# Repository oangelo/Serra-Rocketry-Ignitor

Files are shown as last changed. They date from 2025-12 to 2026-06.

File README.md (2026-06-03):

# Serra Rocketry Ignitor

Sistema de ignicao remota para foguetes experimentais.

## Visao Geral

Duas estacoes independentes se comunicam via LoRa 433 MHz:

| Estacao | Funcao | MCU |
| --- | --- | --- |
| Comando | Operacao remota e seguranca | Raspberry Pi Pico |
| Ignicao | Acionamento do ignitor | ESP32-C3 SuperMini ou Raspberry Pi Pico |

## Sequencia de Ignicao

1. Operador segura o botao por 5 s.
2. Comando transmite `ARM_CONFIRMED` continuamente.
3. Ignicao executa contagem regressiva (5 bipes).
4. Rele aciona por 2 s.
5. Ignicao envia `IGNITION_COMPLETE`.

## Comece Aqui

| Passo | Guia |
| --- | --- |
| 1. Montar | [docs/INSTALL.md](./docs/INSTALL.md) |
| 2. Gravar firmware | [docs/README_ENVIO.md](./docs/README_ENVIO.md) |
| 3. Testar | [test/README.md](./test/README.md) |
| 4. Diagnosticar problemas | [docs/troubleshooting.md](./docs/troubleshooting.md) |

## Estrutura do Repositorio

```text
ignitor/
├── docs/                 # Guias e referencias
├── firmware/
│   ├── micropython/      # Scripts oficiais (.py)
│   └── data/             # Arquivos web/auxiliares
├── hardware/             # BOM, pinagem e materiais fisicos
├── software/             # Legado/compatibilidade
└── test/                 # Scripts e procedimentos de teste
```

## Componentes Principais

| Qtd | Componente | Uso |
| --- | --- | --- |
| 1 | Raspberry Pi Pico | Estacao de Comando |
| 1 | ESP32-C3 SuperMini | Estacao de Ignicao (principal) |
| 2 | Modulo LoRa SX1278 | Comunicacao 433 MHz |
| 2 | LED amarelo 5mm | Status de link |
| 2 | LED vermelho 5mm | Status de ignicao |
| 2 | Buzzer ativo 5V | Feedback sonoro |
| 1 | Botao de ignicao 22 mm | Acionamento |
| 1 | Rele/MOSFET | Saida para ignitor |
| 2 | Modulo TP4056 | Carga de bateria |

Pinagem completa e BOM: [hardware/README.md](./hardware/README.md).

## Regras de Seguranca

- Botao de ignicao deve ser momentaneo (sem trava).
- O comando precisa ser mantido pelos 5 s completos.
- Perda de sinal por mais de 500 ms deve abortar.
- Sempre usar carga dummy antes de ignitor real.
- Sempre conectar antena LoRa antes de energizar.
- Manter distancia minima de 10 m entre operador e foguete.

## Projeto

Projeto da [Serra Rocketry](https://github.com/Serra-Rocketry).

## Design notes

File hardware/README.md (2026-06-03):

# Hardware - Serra Rocketry Ignitor

## Arquitetura

O sistema possui duas estacoes independentes conectadas por LoRa 433 MHz:

- Estacao de Comando: operada pelo usuario em area segura.
- Estacao de Ignicao: fica proxima ao foguete e aciona o ignitor.

## Lista de Componentes (BOM)

| Item | Qtd | Aplicacao | Observacao |
| --- | --- | --- | --- |
| Raspberry Pi Pico | 1 | Estacao de Comando | MCU RP2040 |
| ESP32-C3 SuperMini | 1 | Estacao de Ignicao | MCU principal de ignicao |
| Modulo LoRa SX1278 433 MHz | 2 | Comando e Ignicao | Um por estacao |
| Antena LoRa 433 MHz | 2 | Comando e Ignicao | Obrigatoria antes de energizar |
| LED amarelo 5 mm | 2 | Status de link | Com resistor |
| LED vermelho 5 mm | 2 | Status de ignicao | Com resistor |
| Buzzer ativo | 2 | Feedback sonoro | Um por estacao |
| Botao de ignicao momentaneo | 1 | Comando | Segurar por 5 s |
| Rele ou MOSFET | 1 | Ignicao | Saida para ignitor |
| TP4056 com protecao | 2 | Carga de bateria | Um por estacao |
| Bateria (Li-ion/LiPo) | 2 | Alimentacao | Definir capacidade |
| Resistores 220 ohms | 4 | LEDs | Dois por estacao |

## Pinagem

### Estacao de Comando - Raspberry Pi Pico

| Pino | Funcao |
| --- | --- |
| GP0 | LoRa MISO |
| GP1 | LoRa CS |
| GP2 | LoRa SCK |
| GP3 | LoRa MOSI |
| GP4 | LoRa RESET |
| GP15 | LoRa DIO0 |
| GP11 | LED amarelo |
| GP12 | LED vermelho |
| GP13 | Botao ignicao |
| GP19 | Buzzer |
| GP25 | LED onboard (link) |

### Estacao de Ignicao - ESP32-C3 SuperMini

Pinagem oficial alinhada ao arquivo `firmware/micropython/estacao_ignicao_esp.py`.

| Pino | Funcao |
| --- | --- |
| GPIO4 | LoRa SCK |
| GPIO6 | LoRa MOSI |
| GPIO5 | LoRa MISO |
| GPIO7 | LoRa CS |
| GPIO3 | LoRa RESET |
| GPIO21 | LoRa DIO0 |
| GPIO20 | LED amarelo |
| GPIO0 | LED vermelho |
| GPIO1 | Buzzer |
| GPIO10 | Rele/MOSFET (ignitor) |
| GPIO8 | LED interno de link |

### Estacao de Ignicao - Raspberry Pi Pico (legado)

| Pino | Funcao |
| --- | --- |
| GP0 | LoRa MISO |
| GP1 | LoRa CS |
| GP2 | LoRa SCK |
| GP3 | LoRa MOSI |
| GP4 | LoRa RESET |
| GP15 | LoRa DIO0 |
| GP11 | LED amarelo |
| GP12 | LED vermelho |
| GP19 | Buzzer |
| GP26 | Rele/MOSFET (ignitor) |
| GP25 | LED onboard (link) |

## Sequencia de Operacao

1. Comando envia `ARM_CONFIRMED` enquanto o botao e mantido.
2. Ignicao confirma com `ACK` e inicia contagem de 5 s.
3. Se houver `ABORT` ou perda de sinal > 500 ms, ciclo e cancelado.
4. Ao final da contagem, saida de ignicao ativa por 2 s.
5. Ignicao envia `IGNITION_COMPLETE`.

## Seguranca

- Sempre conectar antena LoRa antes de energizar.
- Usar botao momentaneo (sem trava).
- Testar com carga dummy antes de ignitor real.
- Manter distancia minima de 10 m em testes operacionais.

## Galeria (Tamanho Padronizado)

Todas as imagens abaixo usam largura padrao de 320 px para manter consistencia visual no documento.

<!-- markdownlint-disable MD033 -->

### Raspberry Pi Pico (Comando)

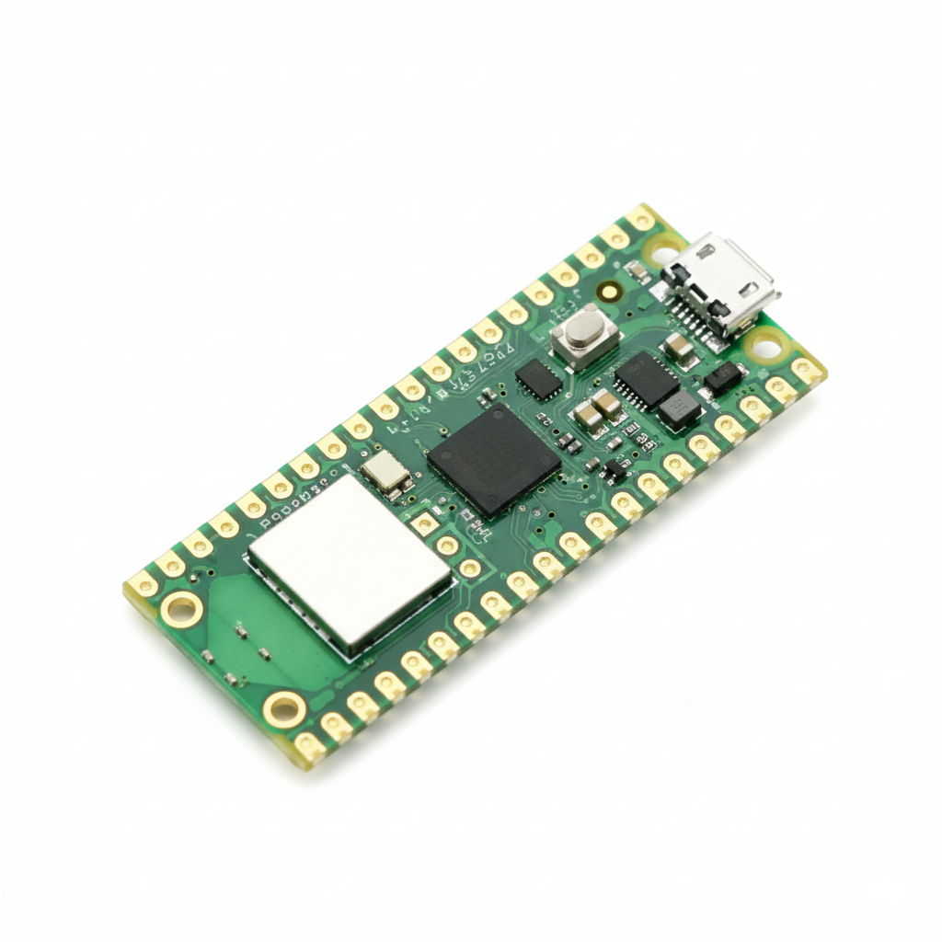
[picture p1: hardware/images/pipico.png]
Raspberry Pi Pico


### Modulo LoRa SX1278

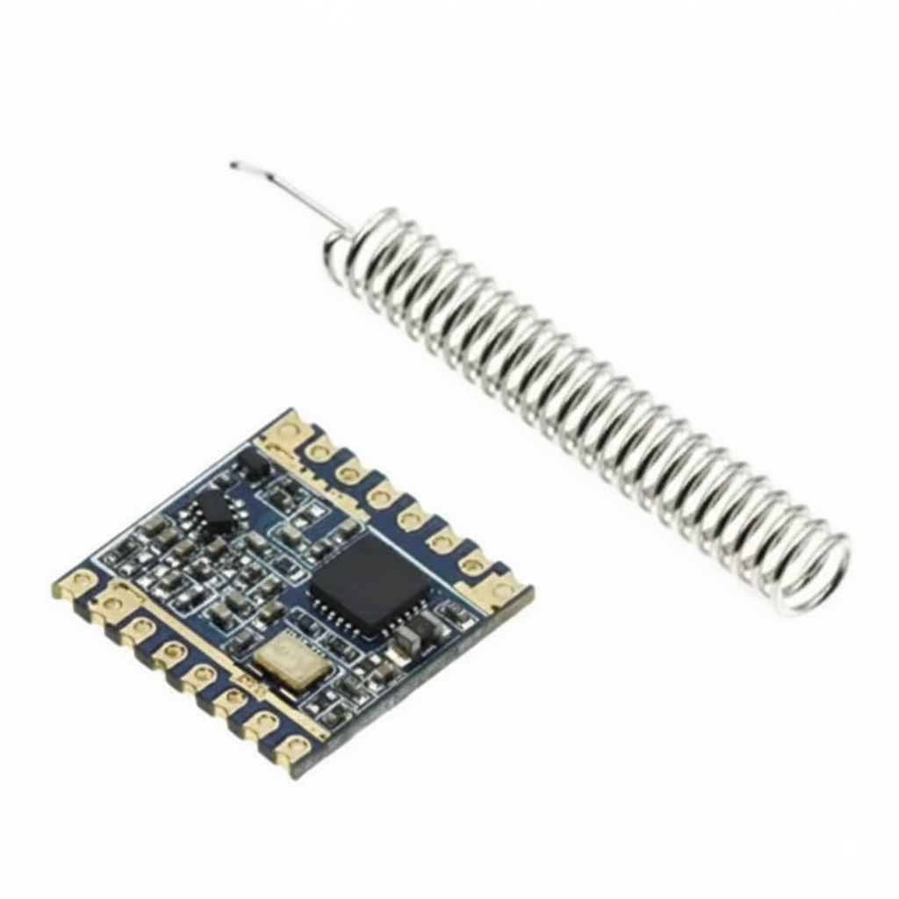
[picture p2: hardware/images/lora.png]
Modulo LoRa SX1278


### Botao de Energia

Botao de energia

### Botao de Ignicao

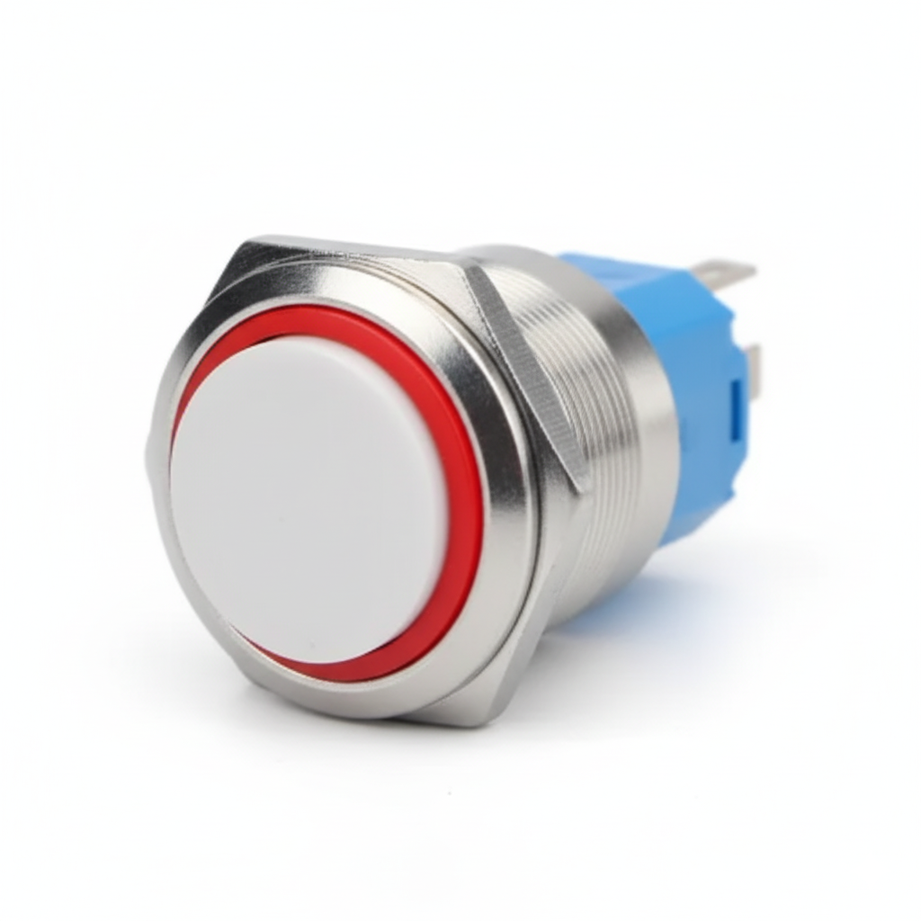
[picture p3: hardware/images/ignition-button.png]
Botao de ignicao


### Esquematico - Estacao de Comando

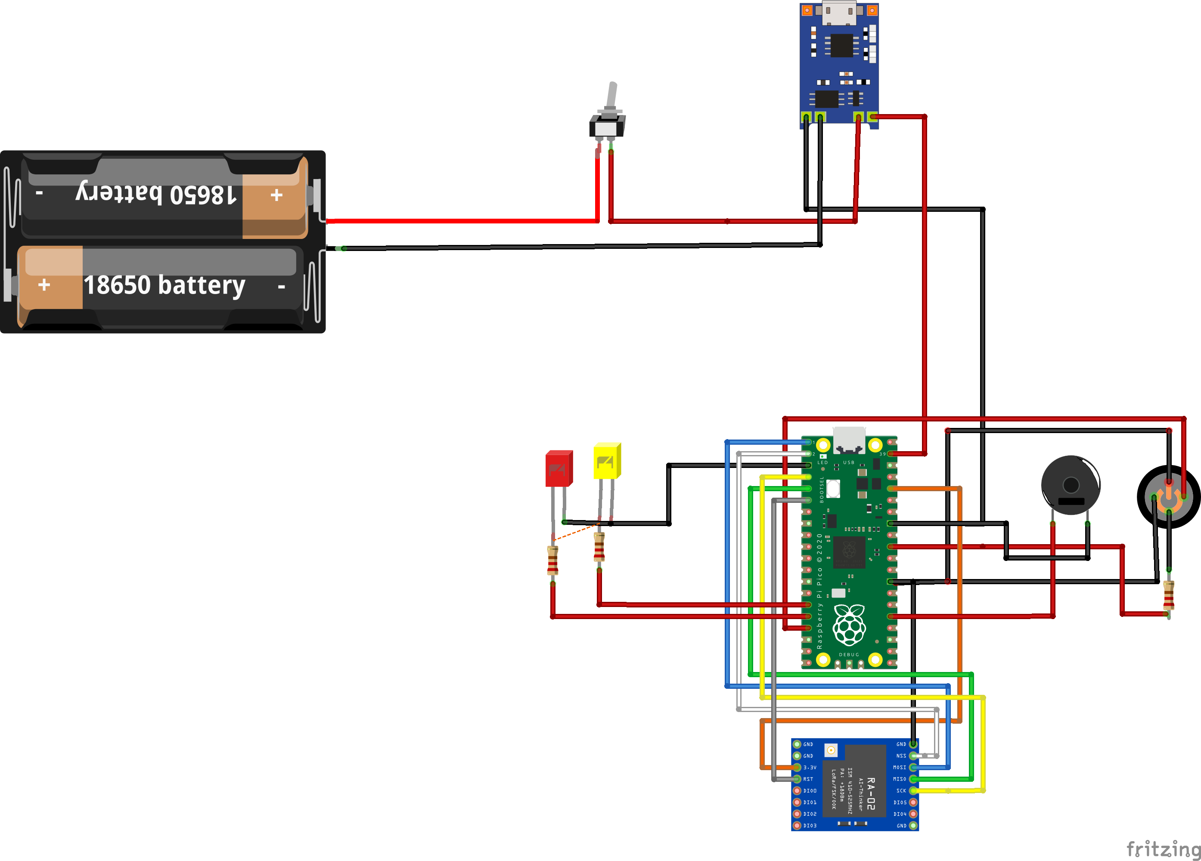
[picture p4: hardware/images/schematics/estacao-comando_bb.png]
Esquematico da estacao de comando


### Esquematico - Estacao de Ignicao

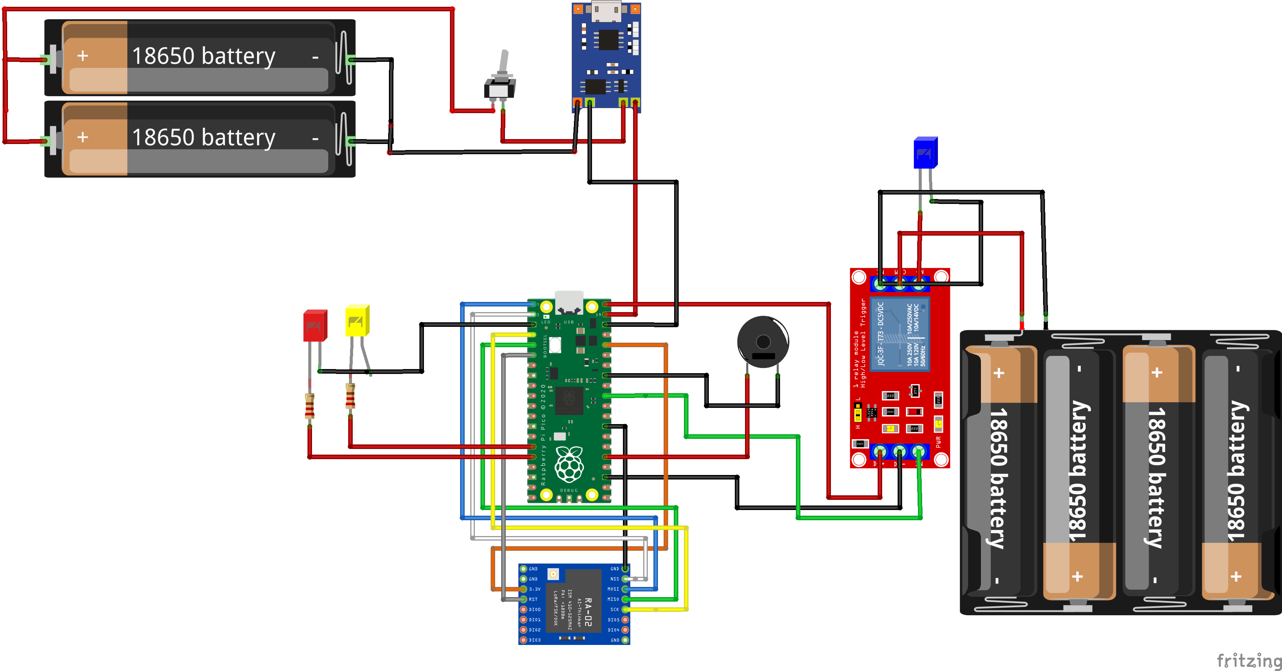
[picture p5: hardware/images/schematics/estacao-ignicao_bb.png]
Esquematico da estacao de ignicao


<!-- markdownlint-enable MD033 -->

## Pastas de Hardware

- [3d_models](./3d_models): modelos 3D dos cases.
- [fritzing](./fritzing): arquivos de esquematico/layout.
- [gerbers](./gerbers): arquivos de fabricacao PCB.
- [images](./images): imagens e esquemas.

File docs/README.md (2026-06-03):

# Documentacao do Ignitor

Guias praticos para montar, operar, testar e manter o sistema.

## Fluxo Recomendado

Montar hardware -> Gravar firmware -> Testar -> Operar.

| Etapa | Documento |
| --- | --- |
| Montagem | [INSTALL.md](./INSTALL.md#3-montagem-de-hardware) |
| Envio de firmware | [README_ENVIO.md](./README_ENVIO.md) |
| Testes de bancada/campo | [../test/README.md](../test/README.md) |
| Troubleshooting | [troubleshooting.md](./troubleshooting.md) |
| Protocolo | [README_API.md](./README_API.md) |
| Registro de resultados | [README_TESTS.md](./README_TESTS.md) |

## Referencias Rapidas

- Pinagem: [../hardware/README.md#pinagem](../hardware/README.md#pinagem)
- BOM: [../hardware/README.md#lista-de-componentes-bom](../hardware/README.md#lista-de-componentes-bom)
- Sequencia operacional: [../hardware/README.md#sequencia-de-operacao](../hardware/README.md#sequencia-de-operacao)

## Avisos Importantes

- Sempre usar carga dummy (lampada/LED) durante testes.
- Nunca energizar modulo LoRa sem antena conectada.
- Manter distancia minima de 10 m do foguete em testes de campo.

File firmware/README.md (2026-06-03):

# Firmware - Serra Rocketry Ignitor

Repositorio de firmware e arquivos auxiliares do projeto.

## Estrutura Atual

```text
firmware/
├── micropython/
│   ├── estacao_comando.py
│   ├── estacao_ignicao.py
│   ├── estacao_ignicao_esp.py
│   ├── sx127x.py
│   └── config_lora.py
└── data/
    ├── index.html
    ├── script.js
    ├── style.css
    └── hammer.min.js
```

## Firmware Oficial (MicroPython)

| Estacao | Arquivo | Placa alvo | Salvar como |
| --- | --- | --- | --- |
| Comando | [micropython/estacao_comando.py](./micropython/estacao_comando.py) | Raspberry Pi Pico | `main.py` |
| Ignicao (principal) | [micropython/estacao_ignicao_esp.py](./micropython/estacao_ignicao_esp.py) | ESP32-C3 SuperMini | `main.py` |
| Ignicao (legado) | [micropython/estacao_ignicao.py](./micropython/estacao_ignicao.py) | Raspberry Pi Pico | `main.py` |

Arquivos de suporte:

- [micropython/sx127x.py](./micropython/sx127x.py)
- [micropython/config_lora.py](./micropython/config_lora.py)

Pinagem completa e BOM:

- [../hardware/README.md](../hardware/README.md#pinagem)

## Pasta data

A pasta [data](./data) contem arquivos web auxiliares para experimentos e interfaces locais.
Ela nao substitui os scripts MicroPython de operacao das estacoes.

## Gravacao nas Placas

Guia rapido de envio:

- [../docs/README_ENVIO.md](../docs/README_ENVIO.md)

Guia de instalacao completo:

- [../docs/INSTALL.md](../docs/INSTALL.md#4-gravar-firmware)

## Debug Serial

```bash
screen /dev/ttyACM0 115200
```

Exemplo de logs esperados:

```text
[LoRa] SX1278 inicializado em 433 MHz.
[CMD] Link com ignicao: OK
[CMD] ACK recebido da base de ignicao.
[CMD] IGNITION_COMPLETE recebido.
```

## Seguranca

- Sempre conectar antena LoRa antes de energizar.
- Testar primeiro com carga dummy (LED/lampada).
- Manter distancia segura durante qualquer teste operacional.

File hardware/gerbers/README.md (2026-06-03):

# Gerbers

Arquivos de fabricacao de PCB (Gerber/Drill) quando houver placa dedicada.

Sugestao de organizacao:

- uma subpasta por revisao de hardware
- incluir README de versao e fornecedor

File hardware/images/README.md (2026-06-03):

# Imagens de Hardware

Imagens de componentes, montagem e documentacao visual.

Subpastas:

- `schematics/` para esquemas exportados

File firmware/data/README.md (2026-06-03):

# Firmware Data

Arquivos auxiliares do firmware legado em Arduino/Web UI:

- `index.html`
- `script.js`
- `style.css`
- `hammer.min.js`

Conteudo usado em experimentos e interfaces locais.

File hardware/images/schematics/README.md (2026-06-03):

# Schematics

Imagens dos esquematicos das estacoes de comando e ignicao.

Use nomes descritivos e mantenha resolucao suficiente para leitura de pinos.

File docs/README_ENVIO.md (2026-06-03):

# Envio de Firmware para Pico e ESP32-C3

Este guia mostra como enviar os scripts MicroPython para as placas do projeto.

## Arquivos por Placa

### Pico da Estacao de Comando

- `firmware/micropython/estacao_comando.py` (salvar como `main.py`)
- `firmware/micropython/sx127x.py` (opcional)
- `firmware/micropython/config_lora.py` (opcional)

### Pico da Estacao de Ignicao

- `firmware/micropython/estacao_ignicao.py` (salvar como `main.py`)
- `firmware/micropython/sx127x.py` (opcional)
- `firmware/micropython/config_lora.py` (opcional)

### ESP32-C3 da Estacao de Ignicao

- `firmware/micropython/estacao_ignicao_esp.py` (salvar como `main.py`)
- `firmware/micropython/sx127x.py` (opcional, existe fallback nativo)

## 1. Descobrir Porta Serial

```bash
ls /dev/ttyACM* /dev/ttyUSB*
```

Exemplo comum:

- Comando: `/dev/ttyACM0`
- Ignicao Pico: `/dev/ttyACM1`
- Ignicao ESP32-C3: `/dev/ttyUSB0`

## 2. Envio com ampy

### 2.1 Estacao de Comando (Pico)

```bash
ampy --port /dev/ttyACM0 put firmware/micropython/estacao_comando.py main.py
ampy --port /dev/ttyACM0 ls
```

### 2.2 Estacao de Ignicao (Pico)

```bash
ampy --port /dev/ttyACM1 put firmware/micropython/estacao_ignicao.py main.py
ampy --port /dev/ttyACM1 ls
```

### 2.3 Estacao de Ignicao (ESP32-C3)

```bash
ampy --port /dev/ttyUSB0 put firmware/micropython/estacao_ignicao_esp.py main.py
ampy --port /dev/ttyUSB0 ls
```

## 3. Envio com Thonny

1. Abrir Thonny.
2. Selecionar interpretador MicroPython da placa.
3. Abrir arquivo em `firmware/micropython/`.
4. Salvar no dispositivo como `main.py`.

## 4. Logs Seriais

```bash
screen /dev/ttyACM0 115200
```

Trocar a porta conforme a placa conectada.

## 5. Regra Importante de Antena

Antes de energizar ou testar, confirme as duas antenas LoRa conectadas e apertadas. Sem antena, o radio pode inicializar, mas o enlace PING/PONG nao fecha de forma confiavel.

## 6. Erros Comuns

### Permissao negada na serial

```bash
sudo usermod -aG dialout $USER
```

Depois, encerre e reabra a sessao.

### Placa nao aparece em `/dev/ttyACM*` ou `/dev/ttyUSB*`

- Trocar cabo USB (dados, nao apenas carga).
- Testar outra porta USB.
- Regravar MicroPython na placa.

## Creditos da Biblioteca LoRa

Projeto baseado/adaptado de:

- [SX127x driver for (Micro)Python on ESP8266/ESP32/Raspberry_Pi](https://github.com/Wei1234c/SX127x_driver_for_MicroPython_on_ESP8266)

Arquivos locais relacionados:

- `firmware/micropython/sx127x.py`
- `firmware/micropython/config_lora.py`

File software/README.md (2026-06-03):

# Software (Legado)

Esta pasta foi mantida por compatibilidade historica.

Os scripts oficiais de firmware MicroPython foram movidos para:

- `../firmware/micropython/`

Nao adicione novos firmwares aqui.

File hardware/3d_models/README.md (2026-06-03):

# Modelos 3D

Arquivos de modelos 3D dos cases e suportes mecanicos do sistema.

Subpastas:

- `comando/`
- `ignição/`

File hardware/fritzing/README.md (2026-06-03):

# Fritzing

Arquivos `.fzz` dos esquemas de montagem das estacoes.

Use esta pasta para manter os diagramas editaveis de protoboard e conexoes.

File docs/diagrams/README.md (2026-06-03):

# Diagramas

Esta pasta concentra diagramas de arquitetura, protocolo e fluxo de operacao.

Padrao recomendado:

- Nome curto e descritivo
- Formato editavel (ex.: `.drawio`, `.mermaid`)
- Exportacao em PNG/SVG quando necessario

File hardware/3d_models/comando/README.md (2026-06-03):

# Modelos 3D - Comando

Modelos STEP da caixa da estacao de comando.

Arquivos tipicos:

- laterais
- tampa superior/inferior

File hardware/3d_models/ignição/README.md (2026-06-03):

# Modelos 3D - Ignicao

Modelos STEP da caixa da estacao de ignicao.

Esta pasta contem as pecas mecanicas para impressao/prototipagem.

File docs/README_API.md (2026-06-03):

# API e Protocolo

> Protocolo de comunicação entre as duas estações via LoRa 433 MHz.

## Camada Física

| Parametro | Valor |
| --- | --- |
| Frequência | 433 MHz |
| Largura de banda | 125 kHz |
| Spreading Factor | 7 |
| Coding Rate | 4/5 |
| Potência TX | 17 dBm |

## Mensagens

| Mensagem | Direcao | Uso |
| --- | --- | --- |
| PING | Comando → Ignição | Teste de conexão |
| PONG | Ignição → Comando | Resposta ao PING |
| ARM_CONFIRMED | Comando → Ignição | Comando mantido (retransmitido a cada 200 ms) |
| ACK | Ignição → Comando | Confirma recebimento e início da contagem |
| ABORT | Comando → Ignição | Cancela imediatamente |
| IGNITION_COMPLETE | Ignição → Comando | Ciclo concluído |

## Diagrama de Estados

```text
        ┌──────────┐
        │  IDLE    │
        └────┬─────┘
             │ PONG
        ┌────▼─────┐
   ┌────│ CONNECTED│◄──┐
   │    └────┬─────┘   │
   │         │ARM_CONFIRMED
   │    ┌───▼──────┐   │ timeout
   │    │ COUNTDOWN │───┴───┘
   │    └────┬─────┘
   │         │ fim (5s)
   │    ┌───▼──────┐
   └───►│ IGNITION │──────► ACK
        └──────────┘
```

## Timeouts

| Parametro | Valor |
| --- | --- |
| Retransmissão ARM_CONFIRMED | 200 ms |
| Timeout de comando (Ignição) | 500 ms |
| Timeout de link (Comando) | 3000 ms |
| Espera após IGNITION_COMPLETE | 3000 ms |

## Regras de Segurança

- Contagem só inicia após `ACK` recebido
- Perda de `ARM_CONFIRMED` por > 500 ms aborta
- Soltar botão envia `ABORT` imediatamente
- Verificação final antes de acionar relé

Consulte [../firmware/micropython/estacao_ignicao_esp.py](../firmware/micropython/estacao_ignicao_esp.py) para implementacao de referencia.

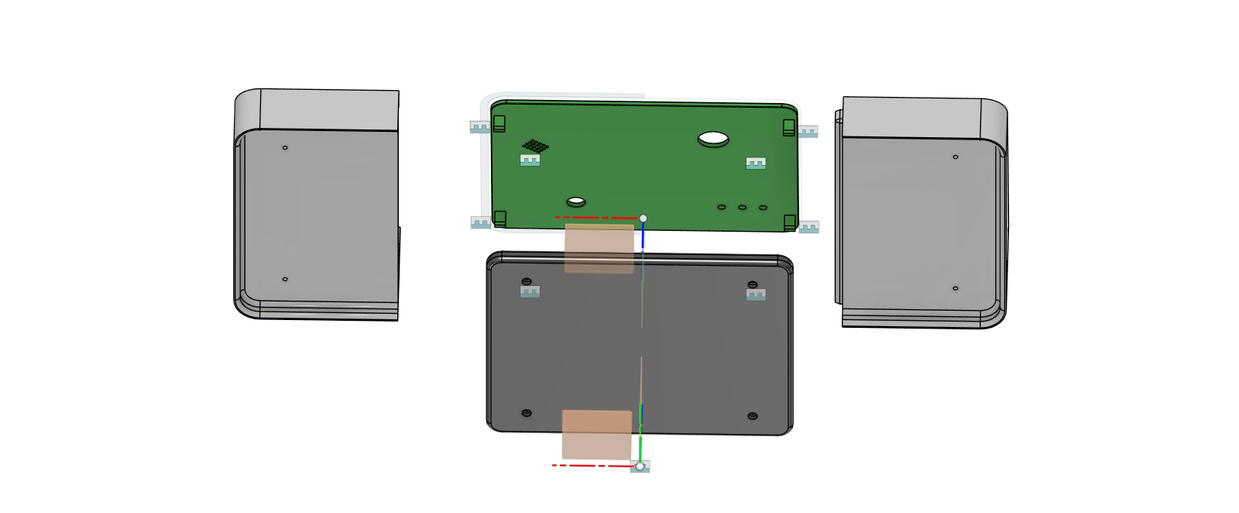
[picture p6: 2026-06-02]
hardware/3d_models/comando/caixa ignitor 2.png

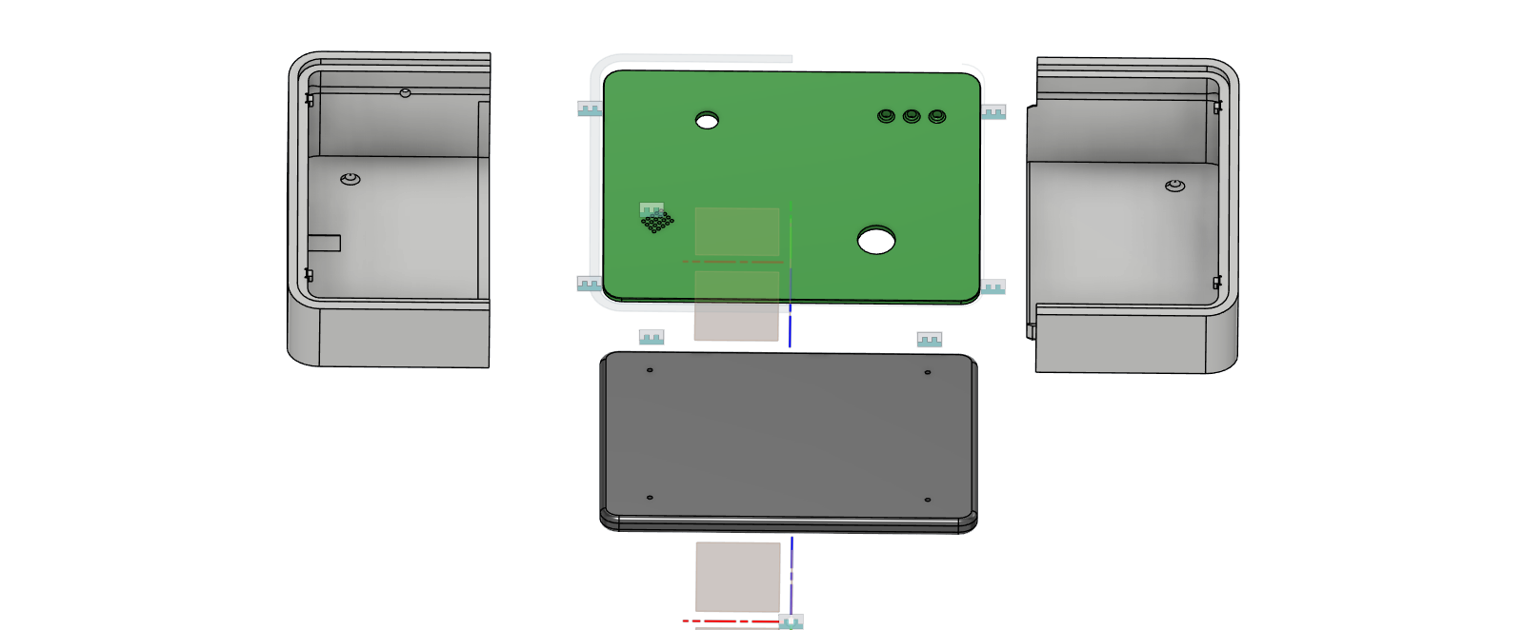
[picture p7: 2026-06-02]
hardware/3d_models/comando/caixa ignitor v16.png

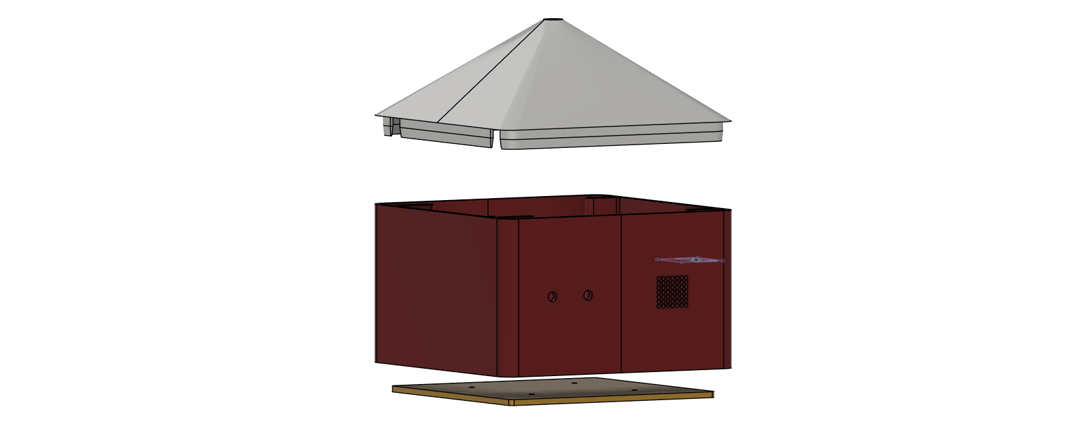
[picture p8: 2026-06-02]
hardware/3d_models/ignição/BASEIGNIÇÃO v9.png

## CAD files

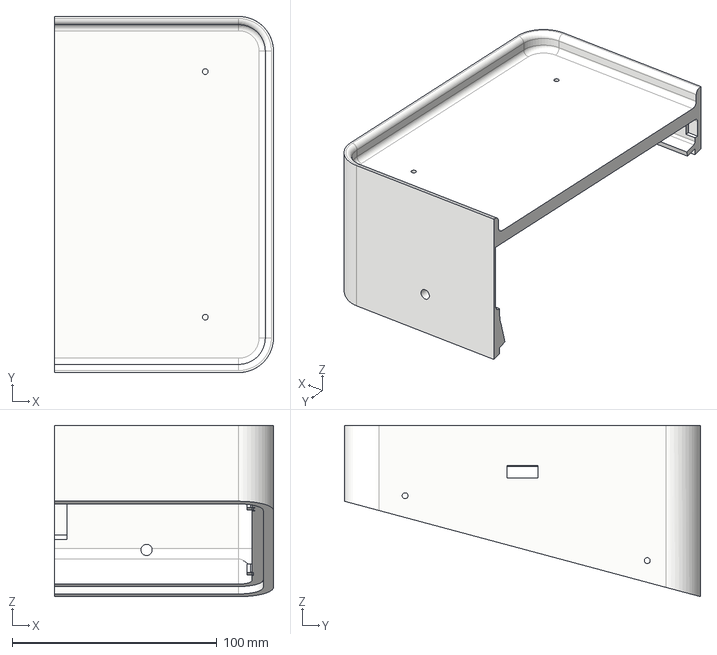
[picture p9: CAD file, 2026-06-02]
hardware/3d_models/comando/lado1.step
107.0 x 174.0 x 83.7 mm

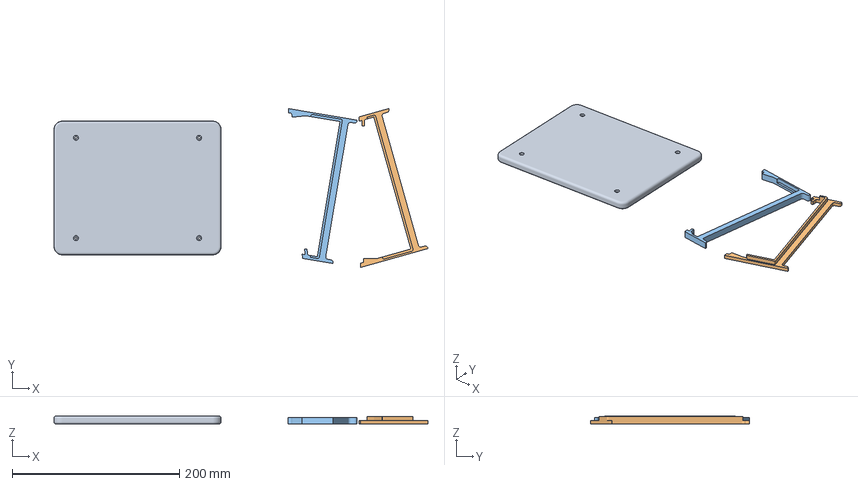
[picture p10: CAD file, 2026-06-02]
hardware/3d_models/ignitorserra.3mf
447.6 x 190.2 x 10.0 mm
tampabaixo.step
lado2.step
lado1.step

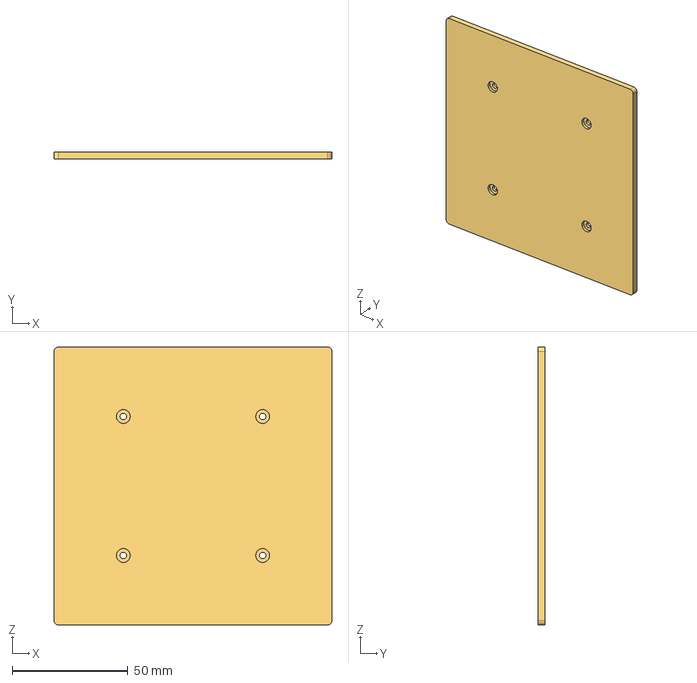
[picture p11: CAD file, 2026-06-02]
hardware/3d_models/ignição/TAMPABAIXO.step
120.0 x 3.00 x 120.0 mm

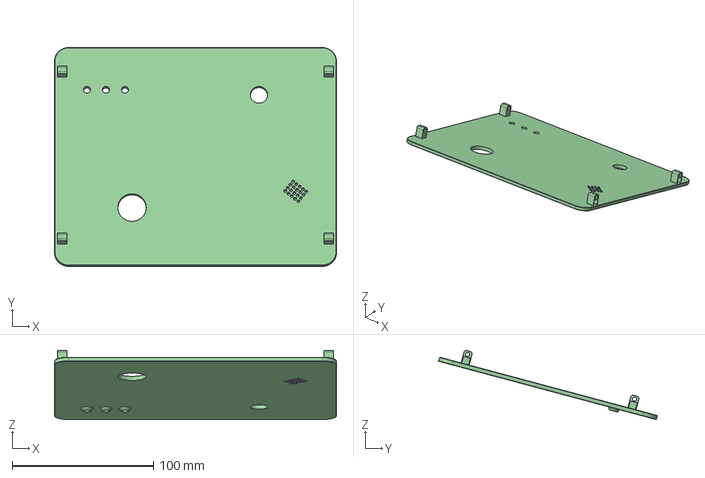
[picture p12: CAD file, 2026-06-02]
hardware/3d_models/comando/tampacima.step
200.0 x 155.2 x 49.0 mm
caixa
Componente3

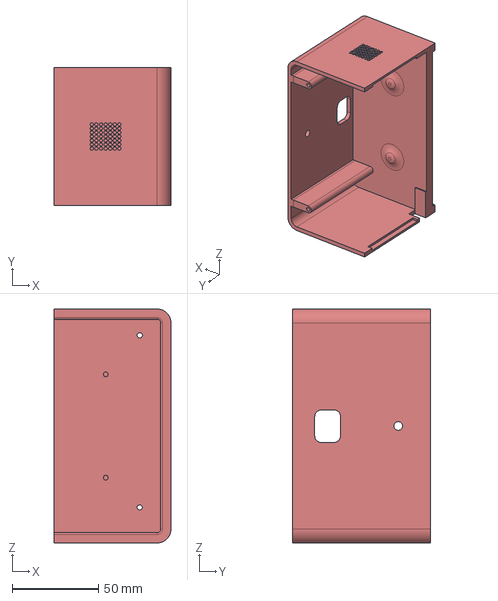
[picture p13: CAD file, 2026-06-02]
hardware/3d_models/ignição/caixapart2.step
68.0 x 80.0 x 136.0 mm

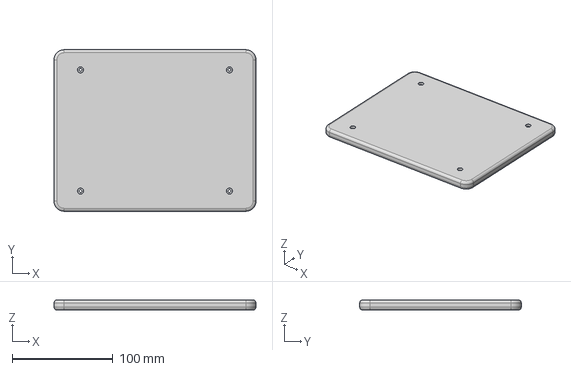
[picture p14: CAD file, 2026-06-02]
hardware/3d_models/comando/tampabaixo.step
200.0 x 160.0 x 10.0 mm

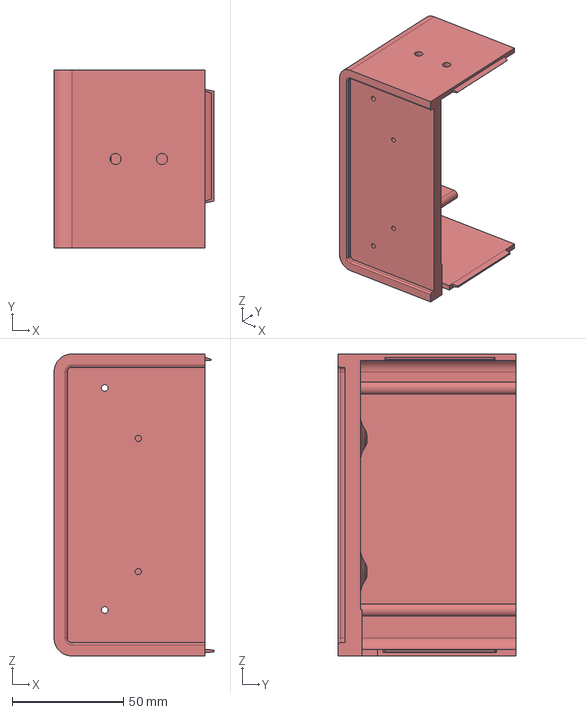
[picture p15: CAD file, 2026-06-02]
hardware/3d_models/ignição/caixapart1.step
72.0 x 80.0 x 136.0 mm

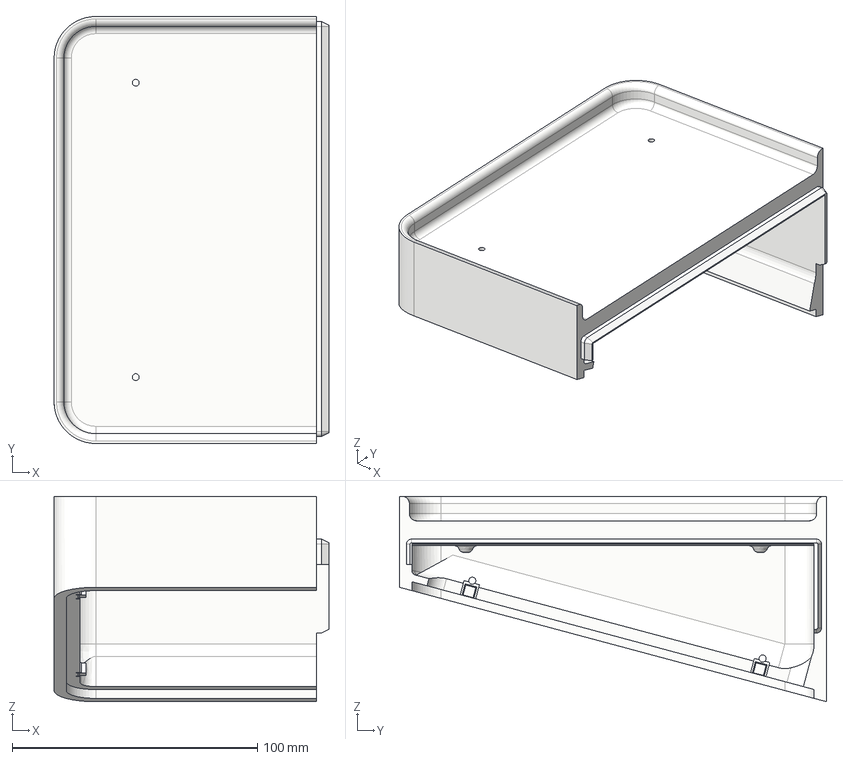
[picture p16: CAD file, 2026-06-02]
hardware/3d_models/comando/lado2.step
112.0 x 174.0 x 83.7 mm

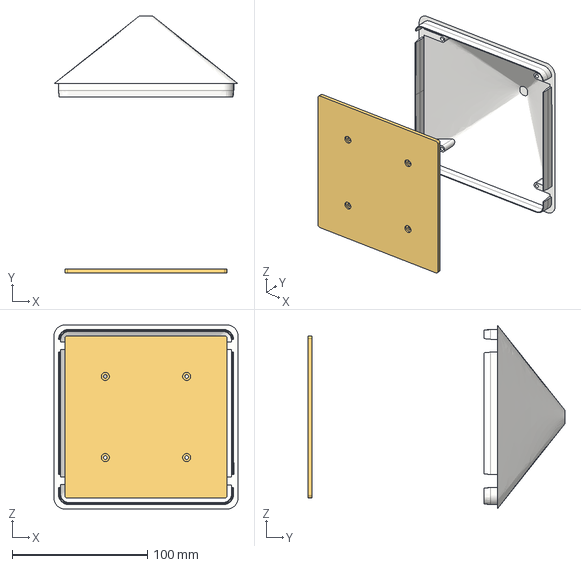
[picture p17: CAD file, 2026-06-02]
hardware/3d_models/ignição/TAMPACIMA.step
136.0 x 190.0 x 136.0 mm

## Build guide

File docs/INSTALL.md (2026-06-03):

# Guia de Instalacao

Resumo: monte -> grave -> teste -> opere.

## Indice

| Secao | Topico |
| --- | --- |
| [1](#1-pre-requisitos) | Pre-requisitos |
| [2](#2-preparar-ambiente) | Preparar ambiente |
| [3](#3-montagem-de-hardware) | Montagem de hardware |
| [4](#4-gravar-firmware) | Gravar firmware |
| [5](#5-validar-operacao) | Validar operacao |
| [6](#6-integracao-com-ignitor-real) | Integracao com ignitor real |
| [7](#7-troubleshooting) | Troubleshooting |

## 1. Pre-requisitos

### Software

- Python 3.8+.
- Dependencias do projeto: `pip install -r requirements.txt`.
- Thonny IDE (recomendado) ou VS Code com extensao MicroPython.

### Hardware

- Multimetro.
- Fonte/bateria adequada.
- Ferramentas de montagem (ferro de solda, estanho, etc.).

## 2. Preparar Ambiente

```bash
git clone https://github.com/Serra-Rocketry/ignitor.git
cd ignitor
pip install -r requirements.txt
```

## 3. Montagem de Hardware

### 3.1 Estacao de Comando

- 1x Raspberry Pi Pico.
- 1x SX1278 433 MHz.
- 2x LEDs + resistores.
- 1x buzzer.
- 1x botao de ignicao.

Pinagem detalhada: [../hardware/README.md](../hardware/README.md#pinagem).

### 3.2 Estacao de Ignicao

- 1x ESP32-C3 SuperMini (ou Pico, variante legada).
- 1x SX1278 433 MHz.
- 2x LEDs + resistores.
- 1x buzzer.
- 1x rele/MOSFET para ignitor.

Pinagem detalhada: [../hardware/README.md](../hardware/README.md#pinagem).

### 3.3 Checklist Antes de Energizar

1. Verificar curto e polaridade com multimetro.
2. Confirmar conexoes SPI.
3. Confirmar antenas LoRa conectadas e apertadas.
4. Nao energizar SX1278 sem antena.

## 4. Gravar Firmware

Scripts oficiais:

- `firmware/micropython/estacao_comando.py`
- `firmware/micropython/estacao_ignicao.py` (Pico)
- `firmware/micropython/estacao_ignicao_esp.py` (ESP32-C3)
- `firmware/micropython/sx127x.py` (compatibilidade)
- `firmware/micropython/config_lora.py` (compatibilidade)

### 4.1 Envio com `ampy`

```bash
# Estacao de Comando (Pico)
ampy --port /dev/ttyACM0 put firmware/micropython/estacao_comando.py main.py

# Estacao de Ignicao (Pico)
ampy --port /dev/ttyACM1 put firmware/micropython/estacao_ignicao.py main.py

# Estacao de Ignicao (ESP32-C3)
ampy --port /dev/ttyUSB0 put firmware/micropython/estacao_ignicao_esp.py main.py
```

## 5. Validar Operacao

1. Ligar estacao de comando.
2. Ligar estacao de ignicao.
3. Confirmar `PING/PONG` no serial e LED amarelo de link.
4. Executar teste com carga dummy no lugar do ignitor.

Se o enlace nao subir, checar antena primeiro.

## 6. Integracao com Ignitor Real

Realizar apenas em ambiente seguro e com procedimento validado.

1. Confirmar continuidade do ignitor.
2. Confirmar antena conectada antes de energizar.
3. Posicionar operador a distancia segura (>= 10 m).
4. Executar sequencia completa.

## 7. Troubleshooting

| Problema | Possivel causa | Acao |
| --- | --- | --- |
| Sem link LoRa | Antena ausente/solta | Reapertar antenas e reiniciar |
| Buzzer sem som | Ligacao incorreta | Verificar pino de buzzer da placa |
| Ignitor nao aciona | Rele/MOSFET | Testar saida com carga dummy |

Detalhes: [troubleshooting.md](./troubleshooting.md).

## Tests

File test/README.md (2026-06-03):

# Plano de Testes

## Objetivos

- Validar comunicacao LoRa bidirecional entre as estacoes.
- Confirmar sequencia de seguranca com botao mantido por 5 s.
- Testar feedback visual (LEDs) e sonoro (buzzers).
- Verificar abort manual e abort por timeout.

## Requisito Inicial

Antes de qualquer teste, confirme as duas antenas LoRa conectadas e apertadas.

## Testes Prioritarios

### 1. Comunicacao LoRa Basica

Objetivo: confirmar `PING/PONG` de forma estavel.

Checklist:

- [ ] Comando envia `PING` e ignicao responde `PONG`.
- [ ] LED amarelo acende nas duas estacoes quando conectadas.
- [ ] Ao desligar uma estacao, timeout de link ocorre conforme esperado.

Procedimento:

1. Ligar as duas estacoes a 1 m.
2. Observar serial e LEDs.
3. Repetir em 10 m, 50 m, 100 m e 500 m.
4. Registrar RSSI e perdas.

### 2. Sequencia de Ignicao Completa

Objetivo: validar contagem e acionamento final.

Checklist:

- [ ] Botao mantido por 5 s.
- [ ] LED vermelho pisca durante contagem.
- [ ] Buzzer da ignicao emite 5 apitos.
- [ ] Saida de ignicao aciona por 2 s.
- [ ] Comando recebe `IGNITION_COMPLETE`.

Procedimento:

1. Conectar carga dummy na saida de ignicao.
2. Segurar botao de ignicao por 5 s.
3. Confirmar acionamento apenas no final da contagem.

### 3. Abort Manual

Objetivo: garantir cancelamento ao soltar o botao.

Checklist:

- [ ] Botao solto antes de 5 s envia `ABORT`.
- [ ] Contagem para imediatamente.
- [ ] Ignitor nao e acionado.

Procedimento:

1. Iniciar contagem.
2. Soltar no 2o ou 3o apito.
3. Repetir cinco vezes.

### 4. Abort por Timeout

Objetivo: abortar em perda de `ARM_CONFIRMED`.

Checklist:

- [ ] Durante contagem, interromper link/comando.
- [ ] Ignicao detecta timeout (> 500 ms).
- [ ] Estado de erro e sinalizado.
- [ ] Ignitor nao e acionado.

### 5. Alcance em Campo

Objetivo: determinar alcance confiavel do enlace.

Checklist:

- [ ] Executar testes em linha de visao.
- [ ] Avaliar 50 m, 100 m, 200 m, 500 m e 1 km.
- [ ] Registrar taxa de sucesso e RSSI.

## Scripts de Bancada

Arquivos da pasta `test/`:

- `mp_lora_radio.py`: modulo comum de radio.
- `mp_teste_conexao.py`: link `PING/PONG` com estatisticas.
- `mp_teste_envio_dados.py`: envio `DATA` com `ACK` e retry.

Uso em duas placas:

1. Copiar `mp_lora_radio.py` e o script desejado.
2. Ajustar `ROLE` no topo.
3. `initiator` e `responder` para teste de conexao.
4. `tx` e `rx` para teste de envio de dados.

Os scripts seguem a configuracao de radio em `firmware/micropython/`.

## Execucao

### Testes Automatizados

```bash
cd test
python run_tests.py --all
python run_tests.py --lora
python run_tests.py --ignition
```

### Testes Manuais

Seguir os procedimentos acima e registrar resultado em `docs/README_TESTS.md`.

## Seguranca

- Nunca usar ignitor real em bancada.
- Sempre usar carga dummy.
- Manter pessoas a pelo menos 10 m.
- Usar EPI adequado durante testes energizados.

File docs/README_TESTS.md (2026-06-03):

# Resultados de Testes

## Matriz de Testes

| ID | Tipo | Descrição | Critério | Status |
|----|---|---|---|---|
| LORA-01 | LoRa | PING/PONG bidirecional | PONG < 500 ms | Pendente |
| LORA-02 | LoRa | RSSI a 50 m | RSSI > -80 dBm | Pendente |
| LORA-03 | LoRa | RSSI a 500 m | RSSI > -120 dBm | Pendente |
| IGN-01 | Ignição | Sequência completa (5 s) | Relé aciona após 5 s | Pendente |
| IGN-02 | Ignição | Contagem de apitos | 5 apitos audíveis | Pendente |
| IGN-03 | Ignição | LEDs | Vermelho pisca → sólido | Pendente |
| ABORT-01 | Segurança | Abort manual | Botão solto cancela | Pendente |
| ABORT-02 | Segurança | Abort por timeout | Perda > 500 ms cancela | Pendente |

**Status**: Pendente | Passou | Falhou

## Registro de Sessões

| Data | ID | Resultado | Distância | RSSI | Observações |
|---|----|---|---|---|---|
| - | - | - | - | - | - |

- Logs salvos em `test/logs/` (não versionado)
- Vídeos/fotos grandes linkados externamente

## Procedimento

Após cada sessão:

1. Preencher registro acima
2. Salvar logs em `test/logs/sessao_YYYYMMDD.csv`
3. Linkar evidências no registro

Consulte [test/README.md](../test/README.md) para procedimentos detalhados.

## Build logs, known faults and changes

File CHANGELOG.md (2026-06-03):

# Changelog

Baseado em [Keep a Changelog](https://keepachangelog.com) e [Versionamento Semântico](https://semver.org).

## [Unreleased]

### Planejado
- Firmware validado
- Testes de campo
- Cases 3D

## [1.0.0] - 2026-04-21

### Adicionado
- **Hardware**: BOM e pinagem para ESP32-C3 SuperMini (Estação de Ignição)
- **Firmware**: `estacao_ignicao_esp.py` para ESP32-C3
- **Protocolo**: Documentação simplificada com diagrama de estados
- **Documentação**: Repositório refatorado (arquivos renomeados, índice consolidado)

### Alterado
- **BOM**: Comando usa Raspberry Pi Pico; Ignição usa ESP32-C3 SuperMini
- **Estrutura**: docs/ renomeado para padrão consistente

## [0.1.0] - 2024-11-14

### Adicionado
- Estrutura inicial do repositório
- Documentação de arquitetura
- BOM e pinagem Raspberry Pi Pico
- Protocolo LoRa 433 MHz
- Guias de instalação e troubleshooting
- Plano de testes

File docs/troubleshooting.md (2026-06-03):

# Troubleshooting

## Problemas Comuns

| Sintoma | Causa provavel | Acao recomendada |
| --- | --- | --- |
| Nao conecta (`PING/PONG`) | Antena ausente/solta | Reconectar as duas antenas e reiniciar |
| Link instavel | Sinal fraco/interferencia | Aproximar estacoes e medir RSSI |
| Buzzer sem som | Pino incorreto ou buzzer danificado | Verificar pino da placa e testar buzzer |
| Botao nao responde | Ligacao/pull-up | Validar continuidade e pino de entrada |
| Ignitor nao aciona | Rele/MOSFET ou pino de saida | Testar saida com carga dummy |
| Contagem aborta | Perda de `ARM_CONFIRMED` | Melhorar enlace e reduzir distancia |

## Checklist Rapido

1. Bateria ok e alimentacao estavel.
2. Antenas conectadas antes de energizar.
3. Firmware correto gravado em cada estacao.
4. Frequencia e pinagem conferidas em `firmware/micropython/estacao_*.py`.
5. Cabo USB de dados para programacao/logs.

## Diagnostico por Serial

Abrir monitor serial em 115200 baud.

Exemplo de fluxo esperado:

```text
[LoRa] SX1278 inicializado em 433 MHz.
[CMD] Link com ignicao: OK
[LoRa TX] -> PING
[LoRa RX] <- PONG
```

## Casos Especificos

### Nao recebe `ARM_CONFIRMED`

1. Confirmar que a estacao de comando esta em estado conectado.
2. Conferir frequencia em ambas as placas.
3. Conferir antena e conexoes SPI.

### Aborta no meio da contagem

1. Manter botao pressionado durante os 5 s.
2. Validar qualidade de sinal (RSSI).
3. Evitar interferencia e aumentar robustez (ex.: SF maior, se necessario).

### Ignitor nao aciona no fim

1. Validar pino de saida com LED/carga dummy.
2. Regravar firmware de ignicao.
3. Revisar acionamento do rele/MOSFET.

## Coleta de Logs

```bash
screen -L /dev/ttyACM0 115200
```

Ou:

```bash
cat /dev/ttyACM0 | tee logs/session_$(date +%Y%m%d_%H%M%S).log
```

## Suporte

Ao abrir issue, incluir:

- Versao do firmware.
- Trecho de configuracao usado.
- Ultimas linhas de log serial.
- Distancia entre estacoes e RSSI.
- Fotos das conexoes.

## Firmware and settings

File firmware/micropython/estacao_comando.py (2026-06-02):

"""
ESTACAO DE COMANDO - SISTEMA DE IGNICAO LoRa

Pinagem SX1278 -> Raspberry Pi Pico
- MOSI: GP3 (pino fisico 5)
- MISO: GP0 (pino fisico 1)
- SCK: GP2 (pino fisico 4)
- CS: GP1 (pino fisico 2)
- RESET: GP4 (pino fisico 6)
- DIO0: GP15 (pino fisico 20)

Perifericos
- LED amarelo: GP11
- LED vermelho: GP12
- Buzzer: GP19
- Botao de ignicao: GP13 (pull-up interno)
"""

from machine import Pin, SPI
import utime


# ─────────────────────────────────────────────────────────────────
#  Driver LoRa (SX127x): prioridade para biblioteca externa,
#  com fallback para driver nativo em SPI se sx127x.py nao existir.
# ─────────────────────────────────────────────────────────────────
USE_SX127X_DRIVER = False

if USE_SX127X_DRIVER:
    try:
        from sx127x import SX127x
        SX127X_DRIVER_AVAILABLE = True
    except Exception as exc:
        SX127X_DRIVER_AVAILABLE = False
        print("[WARN] sx127x indisponivel ({}) - usando driver nativo SX1278.".format(exc))
else:
    SX127X_DRIVER_AVAILABLE = False
    print("[BOOT] Driver nativo SX1278 selecionado (sx127x desativado).")


# ╔══════════════════════════════════════════════════════════════╗
# ║                     CONFIGURAÇÕES                           ║
# ╚══════════════════════════════════════════════════════════════╝

# ── Pinos SPI / LoRa ─────────────────────────────────────────────
PIN_MOSI  = 3
PIN_MISO  = 0
PIN_SCK   = 2
PIN_CS    = 1
PIN_RESET = 4
PIN_DIO0  = 15

# ── Periféricos ──────────────────────────────────────────────────
PIN_LED_YELLOW = 11  # status de conexao e armamento
PIN_LED_RED    = 12  # acende fixo ao receber ACK
PIN_BUZZER     = 19  # bipes de alerta
PIN_BUTTON     = 13  # botao momentaneo (active-low, pull-up)
PIN_LED_LINK   = 25  # LED onboard: indica status de link LoRa

# ── Tempos (ms) ──────────────────────────────────────────────────
HOLD_REQUIRED_MS   = 5_000   # tempo que o botão deve ficar pressionado
DEBOUNCE_MS        = 50      # janela de debounce
BLINK_INTERVAL_MS  = 250     # cadência do LED amarelo / buzzer
ACK_TIMEOUT_MS     = 2_000   # aguarda ACK por este tempo após ARM_CONFIRMED
RETRANSMIT_MS      = 200     # intervalo entre re-envios do ARM_CONFIRMED
PING_INTERVAL_MS   = 1_000   # intervalo de PING para teste de conexao
LINK_TIMEOUT_MS    = 3_000   # sem PONG neste tempo = sem conexao
LINK_BLINK_MS      = 250     # pisca LED de link enquanto desconectado
FINALIZE_DELAY_MS  = 3_000   # espera apos ignicao concluida

# ── Mensagens LoRa ───────────────────────────────────────────────
MSG_ARM    = "ARM_CONFIRMED"
MSG_ABORT  = "ABORT"
MSG_ACK    = "ACK"
MSG_DONE   = "IGNITION_COMPLETE"
MSG_PING   = "PING"
MSG_PONG   = "PONG"

# ── Parâmetros LoRa (SX1278 @ 433 MHz) ──────────────────────────
LORA_PARAMS = {
    "frequency"         : 433e6,
    "bandwidth"         : 125e3,
    "spreading_factor"  : 7,
    "coding_rate"       : 5,        # 4/5
    "output_power"      : 17,       # dBm (máx 20)
    "rx_crc"            : True,
}

# ── Registradores e flags do SX1278 (fallback nativo) ──────────
REG_FIFO            = 0x00
REG_OP_MODE         = 0x01
REG_FRF_MSB         = 0x06
REG_FRF_MID         = 0x07
REG_FRF_LSB         = 0x08
REG_PA_CONFIG       = 0x09
REG_LNA             = 0x0C
REG_FIFO_ADDR_PTR   = 0x0D
REG_FIFO_TX_BASE    = 0x0E
REG_FIFO_RX_BASE    = 0x0F
REG_FIFO_RX_CURRENT = 0x10
REG_IRQ_FLAGS       = 0x12
REG_RX_NB_BYTES     = 0x13
REG_MODEM_CONFIG1   = 0x1D
REG_MODEM_CONFIG2   = 0x1E
REG_PREAMBLE_MSB    = 0x20
REG_PREAMBLE_LSB    = 0x21
REG_PAYLOAD_LENGTH  = 0x22
REG_MODEM_CONFIG3   = 0x26
REG_SYNC_WORD       = 0x39
REG_VERSION         = 0x42

MODE_SLEEP   = 0x00
MODE_STDBY   = 0x01
MODE_TX      = 0x03
MODE_RX_CONT = 0x05
MODE_LORA    = 0x80

IRQ_RX_DONE           = 0x40
IRQ_TX_DONE           = 0x08
IRQ_PAYLOAD_CRC_ERROR = 0x20


# ╔══════════════════════════════════════════════════════════════╗
# ║                    ESTADOS DA MÁQUINA                       ║
# ╚══════════════════════════════════════════════════════════════╝
class State:
    # Estado inicial: aguardando a pressão do botão de ignição.
    IDLE        = "IDLE"
    # Estado de armamento: o botão está pressionado e o sistema conta 5 segundos.
    ARMING      = "ARMING"
    # Estado de transmissão: envia repetidamente o comando de armamento.
    TRANSMITTING = "TRANSMITTING"
    # Estado de confirmação: ignicao concluida no receptor.
    CONFIRMED   = "CONFIRMED"
    # Estado de aborto: envia ABORT para o receptor e retorna a IDLE.
    ABORTING    = "ABORTING"


# ╔══════════════════════════════════════════════════════════════╗
# ║                  DRIVER LoRa (wrapper)                      ║
# ╚══════════════════════════════════════════════════════════════╝
class LoRaRadio:
    """
    Abstracao sobre o radio SX1278.

    Ordem de tentativa:
    1) Driver externo sx127x.py (se instalado);
    2) Driver nativo por registradores SPI;
    3) Modo mock (sem transmissao real).
    """

    def __init__(self):
        self._lora = None
        self._backend = "mock"

        self._spi = SPI(
            0,
            baudrate=1_000_000,
            polarity=0,
            phase=0,
            sck=Pin(PIN_SCK),
            mosi=Pin(PIN_MOSI),
            miso=Pin(PIN_MISO),
        )
        self._cs = Pin(PIN_CS, Pin.OUT, value=1)
        self._reset = Pin(PIN_RESET, Pin.OUT, value=1)
        self._dio0 = Pin(PIN_DIO0, Pin.IN)

        if SX127X_DRIVER_AVAILABLE:
            try:
                self._lora = SX127x(
                    self._spi,
                    pins={
                        "cs"    : self._cs,
                        "reset" : self._reset,
                        "dio0"  : self._dio0,
                    },
                    parameters=LORA_PARAMS,
                )
                self._backend = "sx127x"
                print("[LoRa] SX1278 inicializado em 433 MHz (driver sx127x).")
                return
            except Exception as exc:
                if "unexpected keyword argument 'pins'" in str(exc):
                    print("[INFO] API sx127x legada detectada - tentando compatibilidade.")
                else:
                    print(f"[WARN] Falha no sx127x padrao ({exc}) - tentando compatibilidade.")
                try:
                    self._lora = self._init_legacy_sx127x()
                    self._backend = "sx127x"
                    print("[LoRa] SX1278 inicializado em 433 MHz (sx127x legacy compat).")
                    return
                except Exception as legacy_exc:
                    print(f"[WARN] Falha na compatibilidade sx127x ({legacy_exc}) - fallback nativo.")

        if self._init_native():
            self._backend = "native"
            print("[LoRa] SX1278 inicializado em 433 MHz (driver nativo SPI).")
        else:
            print("[LoRa] Modo MOCK ativo (sem resposta do SX1278).")

    def _legacy_transfer(self, pin, address, value=0x00):
        response = bytearray(1)
        pin.value(0)
        self._spi.write(bytes([address]))
        self._spi.write_readinto(bytes([value]), response)
        pin.value(1)
        return response

    def _init_legacy_sx127x(self):
        legacy_params = {
            "frequency"      : int(LORA_PARAMS["frequency"]),
            "tx_power_level" : int(LORA_PARAMS["output_power"]),
            "signal_bandwidth": int(LORA_PARAMS["bandwidth"]),
            "spreading_factor": int(LORA_PARAMS["spreading_factor"]),
            "coding_rate"    : int(LORA_PARAMS["coding_rate"]),
            "preamble_length" : 8,
            "implicitHeader" : False,
            "sync_word"      : 0x12,
            "enable_CRC"     : bool(LORA_PARAMS["rx_crc"]),
        }

        radio = SX127x(parameters=legacy_params)
        radio.pin_ss = self._cs
        radio.pin_RxDone = None
        radio.transfer = self._legacy_transfer
        if hasattr(radio, "init"):
            radio.init()
        return radio

    def _sx_received_packet(self):
        if not self._lora:
            return False

        if hasattr(self._lora, "received_packet"):
            return bool(self._lora.received_packet())

        if hasattr(self._lora, "receivedPacket"):
            return bool(self._lora.receivedPacket())

        return False

    def _sx_read_payload(self):
        if not self._lora or not hasattr(self._lora, "read_payload"):
            return None

        try:
            return self._lora.read_payload(with_header=False)
        except TypeError:
            return self._lora.read_payload()

    def _native_write_reg(self, reg, value):
        self._cs.value(0)
        self._spi.write(bytes([reg | 0x80, value & 0xFF]))
        self._cs.value(1)

    def _native_read_reg(self, reg):
        self._cs.value(0)
        self._spi.write(bytes([reg & 0x7F]))
        result = self._spi.read(1)
        self._cs.value(1)
        return result[0]

    def _native_read_buf(self, reg, length):
        self._cs.value(0)
        self._spi.write(bytes([reg & 0x7F]))
        result = self._spi.read(length)
        self._cs.value(1)
        return result

    def _native_write_fifo(self, payload):
        self._cs.value(0)
        self._spi.write(bytes([REG_FIFO | 0x80]))
        self._spi.write(payload)
        self._cs.value(1)

    def _native_reset(self):
        self._reset.value(0)
        utime.sleep_ms(10)
        self._reset.value(1)
        utime.sleep_ms(10)

    def _init_native(self):
        self._native_reset()

        version = self._native_read_reg(REG_VERSION)
        if version != 0x12:
            print(f"[WARN] SX1278 nao detectado no driver nativo (REG_VERSION=0x{version:02X}).")
            return False

        self._native_write_reg(REG_OP_MODE, MODE_LORA | MODE_SLEEP)
        utime.sleep_ms(10)

        frf = int((int(LORA_PARAMS["frequency"]) * (1 << 19)) / 32_000_000)
        self._native_write_reg(REG_FRF_MSB, (frf >> 16) & 0xFF)
        self._native_write_reg(REG_FRF_MID, (frf >> 8) & 0xFF)
        self._native_write_reg(REG_FRF_LSB, frf & 0xFF)

        self._native_write_reg(REG_PA_CONFIG, 0x8F)
        self._native_write_reg(REG_LNA, 0x23)
        self._native_write_reg(REG_MODEM_CONFIG1, 0x72)
        self._native_write_reg(REG_MODEM_CONFIG2, 0x74)
        self._native_write_reg(REG_MODEM_CONFIG3, 0x04)
        self._native_write_reg(REG_PREAMBLE_MSB, 0x00)
        self._native_write_reg(REG_PREAMBLE_LSB, 0x08)
        self._native_write_reg(REG_SYNC_WORD, 0x12)
        self._native_write_reg(REG_FIFO_TX_BASE, 0x00)
        self._native_write_reg(REG_FIFO_RX_BASE, 0x00)

        self._native_write_reg(REG_OP_MODE, MODE_LORA | MODE_RX_CONT)
        utime.sleep_ms(10)
        return True

    def _native_send_packet(self, payload):
        if not payload:
            return

        self._native_write_reg(REG_OP_MODE, MODE_LORA | MODE_STDBY)
        self._native_write_reg(REG_FIFO_ADDR_PTR, 0x00)
        self._native_write_reg(REG_PAYLOAD_LENGTH, len(payload))
        self._native_write_fifo(payload)
        self._native_write_reg(REG_IRQ_FLAGS, 0xFF)

        self._native_write_reg(REG_OP_MODE, MODE_LORA | MODE_TX)

        t0 = utime.ticks_ms()
        tx_done = False
        while utime.ticks_diff(utime.ticks_ms(), t0) < 300:
            if self._native_read_reg(REG_IRQ_FLAGS) & IRQ_TX_DONE:
                tx_done = True
                break
            utime.sleep_ms(1)

        self._native_write_reg(REG_IRQ_FLAGS, 0xFF)
        self._native_write_reg(REG_OP_MODE, MODE_LORA | MODE_RX_CONT)

        if not tx_done:
            print("[WARN] Timeout aguardando TX_DONE no SX1278.")

    def _native_receive_packet(self):
        flags = self._native_read_reg(REG_IRQ_FLAGS)
        if not (flags & IRQ_RX_DONE):
            return None

        self._native_write_reg(REG_IRQ_FLAGS, 0xFF)

        if flags & IRQ_PAYLOAD_CRC_ERROR:
            return None

        nb_bytes = self._native_read_reg(REG_RX_NB_BYTES)
        current_addr = self._native_read_reg(REG_FIFO_RX_CURRENT)
        self._native_write_reg(REG_FIFO_ADDR_PTR, current_addr)
        raw = self._native_read_buf(REG_FIFO, nb_bytes)

        try:
            return raw.decode("utf-8", "ignore").strip()
        except Exception:
            return None

    def send(self, message):
        """Transmite uma mensagem pela interface LoRa e mostra log local."""
        try:
            if self._backend == "sx127x":
                self._lora.println(message)
            elif self._backend == "native":
                self._native_send_packet(message.encode("utf-8"))
        except Exception as exc:
            print(f"[WARN] Falha no envio LoRa ({self._backend}): {exc}")
        print(f"[LoRa TX] → {message}")

    @property
    def backend(self):
        return self._backend

    def receive(self):
        """
        Lê um pacote LoRa não bloqueante, se houver.

        Retorna a mensagem decodificada ou None quando não há nenhum pacote.
        """
        try:
            if self._backend == "sx127x" and self._sx_received_packet():
                payload = self._sx_read_payload()
                if payload is None:
                    return None
                msg = bytes(payload).decode("utf-8", "ignore").strip()
                print(f"[LoRa RX] ← {msg}")
                return msg

            if self._backend == "native":
                msg = self._native_receive_packet()
                if msg:
                    print(f"[LoRa RX] ← {msg}")
                    return msg
        except Exception as exc:
            print(f"[WARN] Falha na leitura LoRa ({self._backend}): {exc}")
        return None


# ╔══════════════════════════════════════════════════════════════╗
# ║                 ESTAÇÃO DE COMANDO                          ║
# ╚══════════════════════════════════════════════════════════════╝
class CommandStation:
    """
    Máquina de estados para a estação de comando.

    Esta classe controla o ciclo de armamento e transmissão de mensagens
    de ignição via LoRa, usando um botão físico e indicadores visuais.

    Fluxo de estados:
    IDLE -> ARMING -> TRANSMITTING -> CONFIRMED -> IDLE
    """

    def __init__(self):
        # Inicializa os componentes físicos e o rádio LoRa.
        self.led_yellow = Pin(PIN_LED_YELLOW, Pin.OUT, value=0)
        self.led_red    = Pin(PIN_LED_RED,    Pin.OUT, value=0)
        self.buzzer     = Pin(PIN_BUZZER,     Pin.OUT, value=0)
        self.led_link   = Pin(PIN_LED_LINK,   Pin.OUT, value=0)
        self.button     = Pin(PIN_BUTTON,     Pin.IN,  Pin.PULL_UP)
        self.lora       = LoRaRadio()
        print(f"[CMD] Backend LoRa ativo: {self.lora.backend}")

        # Estado atual da máquina e estado anterior reservado para futura expansão.
        self.state       = State.IDLE
        self._prev_state = None

        # Tempos de controle usados para armamento, piscar e transmissão.
        self._press_start_ms  = 0    # instante em que o botão foi pressionado
        self._last_blink_ms   = 0    # instante do último piscar do LED/buzzer
        self._last_tx_ms      = 0    # instante do último envio de ARM_CONFIRMED
        self._tx_start_ms     = 0    # instante do início da fase de transmissão
        self._finalize_start_ms = 0  # inicio da janela de finalizacao
        self._ack_received = False

        # Debounce do botão para evitar leituras falsas.
        self._last_btn_change_ms = 0
        self._btn_stable_state   = True   # True significa botão solto (pull-up ativo)

        # Estado de toggle para o efeito de piscar.
        self._blink_on = False

        # Estado de link com a estacao de ignicao.
        self._link_ok = False
        self._last_ping_ms = 0
        self._last_pong_ms = None
        self._last_no_link_warn_ms = 0
        self._last_link_blink_ms = 0
        self._link_led_on = False
        self._last_mock_warn_ms = 0

    # ─────────────────────────────────────────
    #  LEITURA COM DEBOUNCE
    # ─────────────────────────────────────────
    def _button_pressed(self) -> bool:
        """
        Retorna True se o botão está estável e pressionado.
        Implementa debounce por tempo: só atualiza o estado estável
        após DEBOUNCE_MS ms de sinal constante.
        """
        raw = self.button.value() == 0   # active-low
        now = utime.ticks_ms()

        if raw != self._btn_stable_state:
            if utime.ticks_diff(now, self._last_btn_change_ms) >= DEBOUNCE_MS:
                self._btn_stable_state   = raw
                self._last_btn_change_ms = now

        return self._btn_stable_state

    # ─────────────────────────────────────────
    #  CONTROLE DE SAÍDAS
    # ─────────────────────────────────────────
    def _all_off(self):
        """Desliga todos os indicadores visuais e sonoros."""
        self.led_yellow.value(0)
        self.led_red.value(0)
        self.buzzer.value(0)
        self._blink_on = False

    def _refresh_link(self, now):
        """Mantem o teste de conexao ativo com PING/PONG."""
        if utime.ticks_diff(now, self._last_ping_ms) >= PING_INTERVAL_MS:
            self._last_ping_ms = now
            self.lora.send(MSG_PING)

        incoming = self.lora.receive()
        if incoming == MSG_PING:
            self.lora.send(MSG_PONG)
            self._last_pong_ms = now
        elif incoming == MSG_PONG:
            self._last_pong_ms = now

        link_was_ok = self._link_ok
        if self._last_pong_ms is None:
            self._link_ok = False
        else:
            self._link_ok = utime.ticks_diff(now, self._last_pong_ms) <= LINK_TIMEOUT_MS
        if self._link_ok != link_was_ok:
            status = "OK" if self._link_ok else "PERDIDO"
            print(f"[CMD] Link com ignicao: {status}")
        if self._link_ok:
            self.led_link.value(1)
            self._link_led_on = True
        elif utime.ticks_diff(now, self._last_link_blink_ms) >= LINK_BLINK_MS:
            self._last_link_blink_ms = now
            self._link_led_on = not self._link_led_on
            self.led_link.value(1 if self._link_led_on else 0)

    def _blink_tick(self):
        """Alterna LED amarelo e buzzer em BLINK_INTERVAL_MS."""
        now = utime.ticks_ms()
        if utime.ticks_diff(now, self._last_blink_ms) >= BLINK_INTERVAL_MS:
            self._last_blink_ms = now
            self._blink_on = not self._blink_on
            self.led_yellow.value(self._blink_on)
            self.buzzer.value(self._blink_on)

    # ─────────────────────────────────────────
    #  TRANSIÇÕES DE ESTADO
    # ─────────────────────────────────────────
    def _enter_idle(self):
        self._all_off()
        if self._link_ok:
            self.led_yellow.value(1)
        self.state = State.IDLE
        print("[CMD] Estado: IDLE — aguardando botão.")

    def _enter_arming(self): 
        self._press_start_ms = utime.ticks_ms()
        self._last_blink_ms  = self._press_start_ms
        self._last_tx_ms     = utime.ticks_add(self._press_start_ms, -RETRANSMIT_MS)
        self._ack_received   = False
        self.state = State.ARMING
        print("[CMD] Estado: ARMING — mantenha o botão por 5 s...")

    def _enter_transmitting(self):
        self._tx_start_ms = utime.ticks_ms()
        self._last_tx_ms  = 0
        self.led_red.value(1 if self._ack_received else 0)
        self.state = State.TRANSMITTING
        print("[CMD] Estado: TRANSMITTING — mantendo ARM_CONFIRMED ativo.")

    def _enter_confirmed(self):
        self._all_off()
        self.led_red.value(1)
        self._finalize_start_ms = utime.ticks_ms()
        self.state = State.CONFIRMED
        print("[CMD] Estado: CONFIRMED — IGNITION_COMPLETE recebido.")

    def _enter_aborting(self):
        self.lora.send(MSG_ABORT)
        self._all_off()
        self.state = State.ABORTING
        print("[CMD] Estado: ABORTING — ABORT enviado.")
        # Retorna imediatamente ao IDLE (sem lógica adicional necessária)
        self._enter_idle()

    # ─────────────────────────────────────────
    #  HANDLERS DE CADA ESTADO
    # ─────────────────────────────────────────
    def _handle_idle(self):
        # Apenas aguarda o início do armamento quando o botão é pressionado.
        now = utime.ticks_ms()
        self._refresh_link(now)

        if self.lora.backend == "mock" and utime.ticks_diff(now, self._last_mock_warn_ms) >= 3000:
            self._last_mock_warn_ms = now
            print("[CMD] RADIO EM MOCK: verifique cabos SPI/energia do SX1278 no comando.")

        if self._link_ok:
            self.led_yellow.value(1)

        if self._button_pressed():
            if not self._link_ok:
                if utime.ticks_diff(now, self._last_no_link_warn_ms) >= 1_000:
                    self._last_no_link_warn_ms = now
                    print("[CMD] Sem link LoRa ativo. Armamento bloqueado.")
                return
            self._enter_arming()

    def _handle_arming(self):
        # Se o botão for solto antes de 5 segundos, o processo é cancelado.
        if not self._button_pressed():
            print("[CMD] Botao solto antes dos 5 s - enviando ABORT.")
            self._enter_aborting()
            return

        now = utime.ticks_ms()

        # Enquanto o botao estiver pressionado, mantem o receptor em contagem.
        if utime.ticks_diff(now, self._last_tx_ms) >= RETRANSMIT_MS:
            self._last_tx_ms = now
            self.lora.send(MSG_ARM)

        incoming = self.lora.receive()
        if incoming == MSG_ACK:
            if not self._ack_received:
                self._ack_received = True
                self.led_red.value(1)
                print("[CMD] ACK recebido da base de ignicao.")
        elif incoming == MSG_DONE:
            self._enter_confirmed()
            return
        elif incoming == MSG_PING:
            self.lora.send(MSG_PONG)
        elif incoming == MSG_PONG:
            self._last_pong_ms = now
            self._link_ok = True
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

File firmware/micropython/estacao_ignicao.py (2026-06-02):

# ==============================================================================
#   ESTAÇÃO DE IGNIÇÃO DE FOGUETES - RECEPTOR/ATUADOR # type: ignore
#   Hardware: Raspberry Pi Pico + LoRa SX1278 (433 MHz) # type: ignore
#   Protocolo: SPI
# ==============================================================================
#
#   MAPEAMENTO DE PINOS: # type: ignore
#   ─────────────────────────────────────────────────────
#   SX1278 (LoRa)         Pico
#   ─────────────────────────────────────────────────────
#   SCK        ──────────  GP2 - 4
#   MOSI       ──────────  GP3 - 5
#   MISO       ──────────  GP0 - 1
#   NSS (CS)   ──────────  GP1 - 2
#   RESET      ──────────  GP4 - 6
#   ─────────────────────────────────────────────────────
#   Relê               ──  GP26   (Ativo em ALTO - NAO INVERTER)
#   Buzzer             ──  GP19
#   LED Vermelho       ──  GP12   (Contagem / Erro)
#   LED Amarelo        ──  GP11   (Conectado / Ativo)
#   ─────────────────────────────────────────────────────
#
#   LÓGICA DE SEGURANÇA:
#   - O Relê é inicializado em BAIXO e SÓ é ativado após
#     5 segundos contínuos de sinal "ARM_CONFIRMED".
#   - Qualquer interrupção do sinal (>500 ms) ou recepção
#     de "ABORT" reseta imediatamente a contagem.
#   - O sistema usa ticks_ms() para temporização não-bloqueante,
#     garantindo que o rádio continue sendo lido durante a contagem.
#   - A estacao inicia diretamente apos energizacao pela chave geral.
# ==============================================================================

import utime
from machine import Pin, SPI

try:
    from sx127x import SX127x
    SX127X_DRIVER_AVAILABLE = True
except Exception as exc:
    SX127X_DRIVER_AVAILABLE = False
    print("[WARN] sx127x indisponivel na Ignicao ({}) - usando driver nativo SX1278.".format(exc))

# =============================================================================
#  DEFINIÇÃO DE PINOS
# =============================================================================
SPI_SCK  = 2
SPI_MOSI = 3
SPI_MISO = 0
SPI_DIO0 = 15  # opcional no driver de biblioteca

# Pinos de controle do SX1278
LORA_CS    = Pin(1, Pin.OUT, value=1)  # NSS: HIGH = modulo desmarcado
LORA_RESET = Pin(4, Pin.OUT, value=1)  # RESET: LOW por 10ms para resetar
LORA_DIO0  = Pin(SPI_DIO0, Pin.IN)

# Ajuste para 0 caso seu modulo de rele seja acionado em nivel baixo.
RELE_ACTIVE_LEVEL    = 1
RELE_INACTIVE_LEVEL  = 0 if RELE_ACTIVE_LEVEL else 1

# Atuadores e Indicadores
PIN_RELE         = Pin(26, Pin.OUT, value=RELE_INACTIVE_LEVEL)
PIN_BUZZER       = Pin(19, Pin.OUT, value=0)
PIN_LED_VERMELHO = Pin(12, Pin.OUT, value=0)  # Vermelho: Pisca em contagem/erro, ON ignicao
PIN_LED_AMARELO  = Pin(11, Pin.OUT, value=0)  # Amarelo: ON quando conectado/ativo
PIN_LED_LINK     = Pin(25, Pin.OUT, value=0)  # LED onboard: status de conexao

def _set_rele(ligado):
    PIN_RELE.value(RELE_ACTIVE_LEVEL if ligado else RELE_INACTIVE_LEVEL)

LORA_PARAMS = {
    "frequency"         : 433e6,
    "bandwidth"         : 125e3,
    "spreading_factor"  : 7,
    "coding_rate"       : 5,
    "output_power"      : 17,
    "rx_crc"            : True,
}

# =============================================================================
#  ENDERECOS DE REGISTRADORES DO SX1278
# =============================================================================

REG_FIFO            = 0x00
REG_OP_MODE         = 0x01
REG_FRF_MSB         = 0x06
REG_FRF_MID         = 0x07
REG_FRF_LSB         = 0x08
REG_PA_CONFIG       = 0x09
REG_LNA             = 0x0C
REG_FIFO_ADDR_PTR   = 0x0D
REG_FIFO_TX_BASE    = 0x0E
REG_FIFO_RX_BASE    = 0x0F
REG_FIFO_RX_CURRENT = 0x10
REG_IRQ_FLAGS       = 0x12
REG_RX_NB_BYTES     = 0x13
REG_MODEM_CONFIG1   = 0x1D
REG_MODEM_CONFIG2   = 0x1E
REG_PREAMBLE_MSB    = 0x20
REG_PREAMBLE_LSB    = 0x21
REG_PAYLOAD_LENGTH  = 0x22
REG_MODEM_CONFIG3   = 0x26
REG_SYNC_WORD       = 0x39
REG_DIO_MAPPING1    = 0x40
REG_VERSION         = 0x42

# Modos de operacao do SX1278
MODE_SLEEP   = 0x00
MODE_STDBY   = 0x01
MODE_TX      = 0x03
MODE_RX_CONT = 0x05
MODE_LORA    = 0x80  # Bit 7 = 1 habilita modo LoRa

# Mascaras de flag de interrupcao (registrador IRQ_FLAGS)
IRQ_RX_DONE = 0x40  # Pacote recebido com sucesso
IRQ_TX_DONE = 0x08  # Transmissao concluida

# =============================================================================
#  INICIALIZACAO DO BARRAMENTO SPI
# =============================================================================

spi = SPI(0,
          baudrate=1_000_000,
          polarity=0,
          phase=0,
          sck=Pin(SPI_SCK),
          mosi=Pin(SPI_MOSI),
          miso=Pin(SPI_MISO))

lora_driver = None
lora_backend = "native"

# =============================================================================
#  FUNCOES SPI DE BAIXO NIVEL
# =============================================================================

def _spi_write(reg, value):
    # Bit 7 = 1 indica operacao de escrita no SX1278
    LORA_CS.value(0)
    spi.write(bytes([reg | 0x80, value]))
    LORA_CS.value(1)

def _spi_read(reg):
    # Bit 7 = 0 indica operacao de leitura
    LORA_CS.value(0)
    spi.write(bytes([reg & 0x7F]))
    result = spi.read(1)
    LORA_CS.value(1)
    return result[0]

def _spi_read_buf(reg, length):
    # Leitura de multiplos bytes consecutivos do FIFO
    LORA_CS.value(0)
    spi.write(bytes([reg & 0x7F]))
    result = spi.read(length)
    LORA_CS.value(1)
    return result


def _toggle_pin(pin):
    """Alterna pinos de forma compativel com firmwares sem Pin.toggle()."""
    pin.value(0 if pin.value() else 1)

def _sx127x_legacy_transfer(pin, address, value=0x00):
    response = bytearray(1)
    pin.value(0)
    spi.write(bytes([address]))
    spi.write_readinto(bytes([value]), response)
    pin.value(1)
    return response

def _init_legacy_sx127x(frequency):
    params = {
        "frequency"      : int(frequency),
        "tx_power_level" : int(LORA_PARAMS["output_power"]),
        "signal_bandwidth": int(LORA_PARAMS["bandwidth"]),
        "spreading_factor": int(LORA_PARAMS["spreading_factor"]),
        "coding_rate"    : int(LORA_PARAMS["coding_rate"]),
        "preamble_length" : 8,
        "implicitHeader" : False,
        "sync_word"      : 0x12,
        "enable_CRC"     : bool(LORA_PARAMS["rx_crc"]),
    }

    radio = SX127x(parameters=params)
    radio.pin_ss = LORA_CS
    radio.pin_RxDone = None
    radio.transfer = _sx127x_legacy_transfer
    if hasattr(radio, "init"):
        radio.init()
    return radio

def _sx127x_packet_available():
    if not lora_driver:
        return False

    if hasattr(lora_driver, "received_packet"):
        return bool(lora_driver.received_packet())

    if hasattr(lora_driver, "receivedPacket"):
        return bool(lora_driver.receivedPacket())

    return False
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

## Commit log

2025-11-12 Update README.md
    adicionei a lista de materiais
2025-11-14 Reestrutura repositório com arquitetura de duas estações
    - Define sistema com Estação de Comando e Estação de Ignição
    - Adiciona documentação completa: instalação, API LoRa, testes, troubleshooting
    - Especifica BOM real: Raspberry Pi Pico, LoRa 915MHz, LEDs, buzzers, botões
    - Documenta sequência de segurança: botão mantido 5s + contagem regressiva
    - Organiza estrutura em: docs/, firmware/, hardware/, test/, software/
    - Remove suposições de sensores e telemetria não planejados
    - Adiciona config.example.h com pinagem e parâmetros de segurança
    - Cria plano de testes focado em comunicação LoRa e procedimentos de abort
2025-12-15 docs(hardware): adiciona imagens dos componentes e atualiza especificações
    - Adiciona imagens: pipico.png, lora.png, power-button.avif, ignition-button.png
    - Corrige frequência LoRa: 915 MHz → 433 MHz (chip SX1268)
    - Atualiza especificações dos botões na BOM
    - Adiciona seção Galeria de Componentes com descrições
    - Renomeia iginition-button.png → ignition-button.png (typo)
2026-06-02 fix: corrido o design das caixas de comando e ignição
    [TAMPABAIXO.step, TAMPACIMA.step, caixapart1.step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]
